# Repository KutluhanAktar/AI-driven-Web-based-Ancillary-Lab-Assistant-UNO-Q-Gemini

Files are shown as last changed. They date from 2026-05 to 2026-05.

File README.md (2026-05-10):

> I developed my portfolio website — kutluhanaktar.com — from scratch and decided to migrate all of my codebase to GitHub to provide a simple and straightforward experimentation or replication method for my proof-of-concept projects. Nonetheless, since I focused on demonstrating my thought process and experiment results thoroughly in the written tutorial format, including but not limited to PCB and 3D model designing steps, I could not provide enough information to fully explain my concepts and instructions via GitHub descriptions only. Thus, I highly recommend inspecting the associated project tutorials and videos on my portfolio website or other platforms (maker communities), i.e., Hackster, Hackaday, and Instructables.

# Original Project Publication Date

**May 10, 2026**

# Description

**Based on Arduino UNO Q, this lab assistant is able to show real-time sensor readings, identify users by fingerprint, recognize lab equipment via object detection, generate AI lessons via Gemini, and talk through its full-fledged web dashboard.**

After hearing about the launch of the brand-new Arduino UNO Q, designed as the first SBC (single-board computer) with Arduino's philosophy of bridging the gap between employing professional development tools and implementing them as novices when creating introductory projects or as experts while prototyping complex mechanisms rapidly yet stably, I thought it would be a great opportunity to redesign my previous AI-driven lab assistant project and enable more developers, beginner or expert, to replicate, experiment, or improve this new AI-based ancillary lab assistant thanks to the built-in Arduino UNO Q features and its beginner-friendly development platform — Arduino App Lab.

As you may know, if you have read one of my previous project tutorials, I prefer building my AIoT projects on the target development boards and environments from scratch and enjoy developing unique methods, applications, and mechanisms to collect custom training data and achieve intended device features, strictly following my methodology of developing proof-of-concept research projects. Nonetheless, in this project, I heavily focused on developing all lab assistant features based on the provided UNO Q and Arduino App Lab characteristics, such as the built-in Bricks, native microprocessor-microcontroller communication procedure, and Linux-oriented SBC board architecture, to ensure that anyone with a UNO Q can effortlessly replicate and examine this lab assistant without needing to have a deep understanding of all aspects of this project; coding, web design, neural network training, LLM-implementation, 3D modeling, etc. In this regard, I hope this project serves as an entry point for developing research projects, encouraging readers to reverse-engineer the features of this AI-driven lab assistant to gain a deeper understanding of AIoT development on the edge.

As I was taking inspiration from my previous lab assistant project, I heavily modified the device structure and added a lot of new features specific to this iteration, for instance, designing a unique PCB (UNO Q shield) for utilizing various lab sensors to conduct LLM-assisted basic lab experiments. After months of hard work, I managed to complete the reimagined AI-driven ancillary lab assistant structure and develop all the features I envisioned on UNO Q by solely employing the Arduino App Lab development environment, providing foundational building blocks (Bricks).

🤖 To build the ancillary lab assistant structure:

✍🏻 I designed a unique PCB as a UNO Q shield (hat) to connect the selected lab sensors and create the analog lab assistant interface, including the capacitive fingerprint sensor.

✍🏻 Then, I modeled 3D parts to design the ancillary lab assistant base, containing the USB camera and the analog interface.

✍🏻 Finally, I designed a modular lab sensor ladder, organizing all sensors and secondary experiment tools, to create a compact but easy-to-use instrument.

🤖 To accomplish all of the ancillary lab assistant features I contemplated, performed by an Arduino App Lab application:

🛠️ I trained an Edge Impulse object detection model to identify various lab equipment.

🛠️ I programmed the MCU (STM32) to collect real-time sensor information and manage the analog lab assistant interface.

🛠️ I developed a feature-rich web dashboard as the primary user interface and control panel of the lab assistant, hosted directly by the Arduino App Lab.

🛠️ I incorporated Google Gemini to enable the lab assistant to generate LLM-based lessons about the detected lab equipment.

🛠️ Thanks to the built-in background Linux MPU-MCU communication service (Arduino Router), I built the interconnected interface background in Python, handling the data transfer between the web dashboard, the analog interface (MCU), and the Qualcomm QRB (MPU) running the essential App Lab Bricks (Docker containers); database registration, inference running, web dashboard (UI) hosting, etc.

🤖 The finalized ancillary lab assistant allows users to:

🔬 create web dashboard accounts and sign in via fingerprint authentication,

🔬 monitor real-time lab sensor readings via the analog interface or the web dashboard,

🔬 inspect LLM-generated sensor guides and experiment tips for each lab sensor via the web dashboard,

🔬 capitalizing on the built-in browser text-to-speech (TTS) module, listen to LLM-generated sensor guides and experiment tips,

🔬 identify lab equipment via the provided Edge Impulse FOMO object detection model,

🔬 use the predefined equipment questions or enter a specific one to generate AI lessons through Google Gemini,

🔬 access the list of LLM-generated lessons assigned to your account on the web dashboard anytime,

🔬 study LLM-generated lessons by reading or listen to them via the TTS module.

# Inspect the project tutorial on:

- **[kutluhanaktar.com](https://www.kutluhanaktar.com/projects/AI_driven_Ancillary_Lab_Assistant_w_UNO_Q_and_Gemini/)**
- **[Hackster](https://www.hackster.io/kutluhan-aktar/ai-driven-web-based-ancillary-lab-assistant-uno-q-gemini-b6d539)**
- **[Instructables](https://www.instructables.com/AI-driven-Web-based-Ancillary-Lab-Assistant-UNO-Q-/)**
- **[Hackaday](https://hackaday.io/project/205671-ai-driven-web-based-lab-assistant-uno-q-gemini)**

pcb_solder_7 <br>

model_design_24_overall <br>

model_design_25_overall <br>

assembly_8_base <br>

assembly_15_base <br>

assembly_50_sensor_ladder <br>

pcb_base_set_2 <br>

pcb_base_set_12_cable_ties <br>

pcb_base_set_13_cable_ties <br>

pcb_connect_test_3 <br>

pcb_connect_test_5 <br>

pcb_connect_test_6 <br>

analog_exp_3_prepare <br>

pcb_connect_test_7 <br>

final_showcase_with_equ_1 <br>

analog_run_2_manual_sensor <br>

web_dashboard_work_2_sensor <br>

web_dashboard_work_4_sensor <br>

analog_run_4_dashboard_sensor <br>

web_dashboard_work_30_sensor_exp_talk <br>

analog_exp_5_pressure <br>

web_dashboard_work_33_sensor_show_exps <br>

analog_exp_7_alcohol <br>

web_dashboard_work_35_sensor_show_exps <br>

analog_exp_9_weight <br>

web_dashboard_work_37_sensor_show_exps <br>

web_dashboard_work_39_sensor_show_exps <br>

analog_exp_11_water <br>

analog_exp_18_gnss_found_signal <br>

analog_exp_20_gnss_found_signal <br>

web_dashboard_work_gnss_found_full_signal_2 <br>

web_dashboard_work_44_gemini_lesson <br>

web_dashboard_work_47_gemini_lesson <br>

analog_account_register_1 <br>

analog_account_register_5 <br>

analog_account_register_6 <br>

analog_lesson_3_prepare <br>

analog_lesson_4_prepare <br>

web_dashboard_work_54_gemini_lesson <br>

web_dashboard_work_55_gemini_lesson <br>

web_dashboard_work_56_gemini_lesson <br>

web_dashboard_work_59_gemini_lesson <br>

web_dashboard_work_60_gemini_lesson <br>

web_dashboard_work_72_gemini_lesson_custom_question <br>

web_dashboard_work_74_gemini_lesson_custom_question <br>

web_dashboard_work_76_gemini_lesson_custom_question <br>

web_dashboard_work_67_save_new_sample <br>

web_dashboard_work_69_save_new_sample <br>

web_dashboard_work_88_signin <br>

analog_account_verify_1_not_f <br>

analog_account_verify_6_success <br>

analog_account_verify_7_success <br>

web_dashboard_work_91_signin <br>

web_dashboard_work_92_signin <br>

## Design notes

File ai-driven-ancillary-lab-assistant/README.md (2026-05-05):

# 🔬 AI-driven Web-based Ancillary Lab Assistant | UNO Q & Gemini

### Based on Arduino UNO Q, this lab assistant is able to show real-time sensor readings, identify users by fingerprint, detect lab equipment via object detection, generate AI lessons via Gemini, and talk through its full-fledged web dashboard.

Please visit the thorough project tutorial on ***Hackster*** for more information:

[Project Tutorial](https://www.hackster.io/kutluhan-aktar/ai-driven-web-based-ancillary-lab-assistant-uno-q-gemini-b6d539)

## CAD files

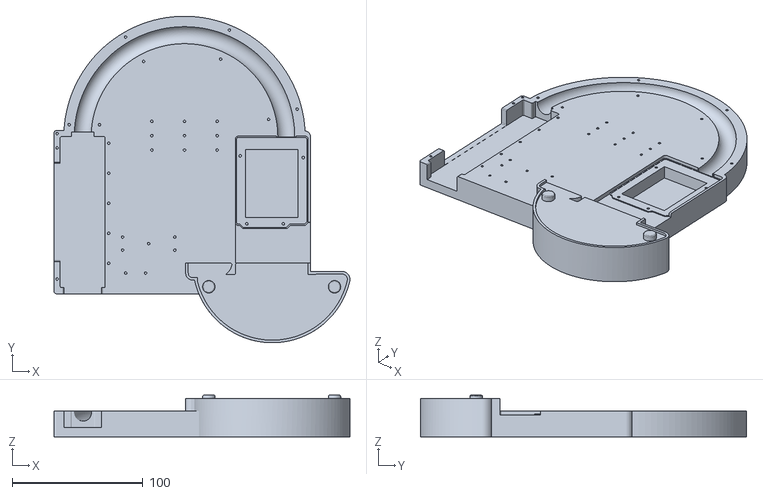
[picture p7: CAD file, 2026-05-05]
3D_part_and_component_design_files/AI_driven_lab_assistant_uno_q v23_AI_driven_lab_assistant_uno_q v23_assistant_base.stl
226.8 x 250.2 x 32.0

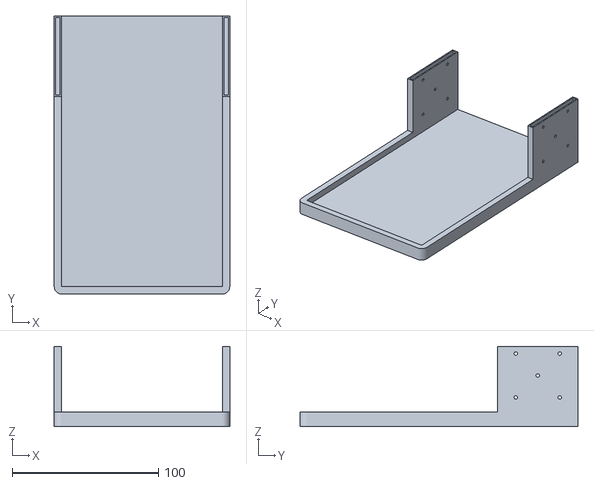
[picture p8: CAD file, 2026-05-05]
3D_part_and_component_design_files/AI_driven_lab_assistant_uno_q v23_AI_driven_lab_assistant_uno_q v23_Lab_Sensors_Ladder_1_sensor_ladder_base.stl
120.0 x 190.0 x 55.0

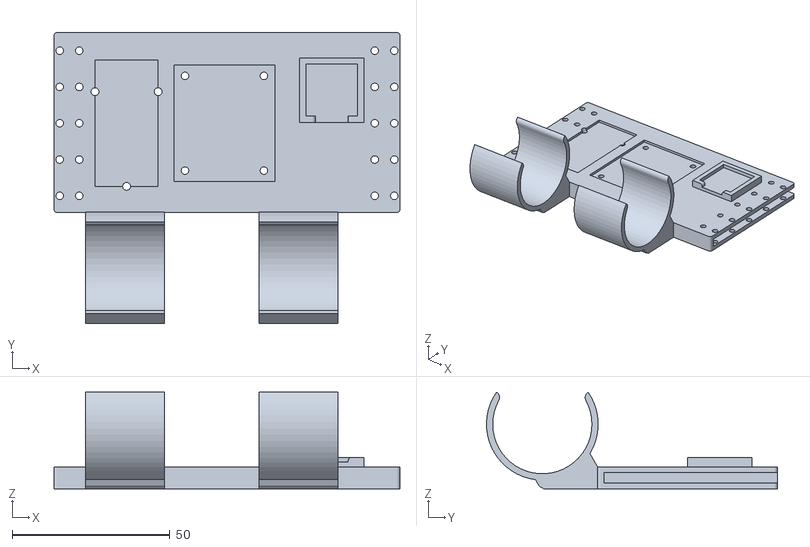
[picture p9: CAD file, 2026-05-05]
3D_part_and_component_design_files/AI_driven_lab_assistant_uno_q v23_AI_driven_lab_assistant_uno_q v23_Lab_Sensors_Ladder_1_row_third.stl
109.6 x 92.2 x 30.7

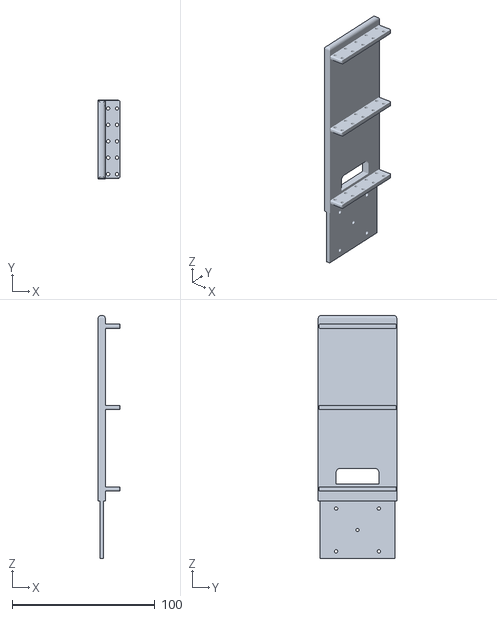
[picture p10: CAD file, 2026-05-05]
3D_part_and_component_design_files/AI_driven_lab_assistant_uno_q v23_AI_driven_lab_assistant_uno_q v23_Lab_Sensors_Ladder_1_ladder_left.stl
15.2 x 55.0 x 170.2

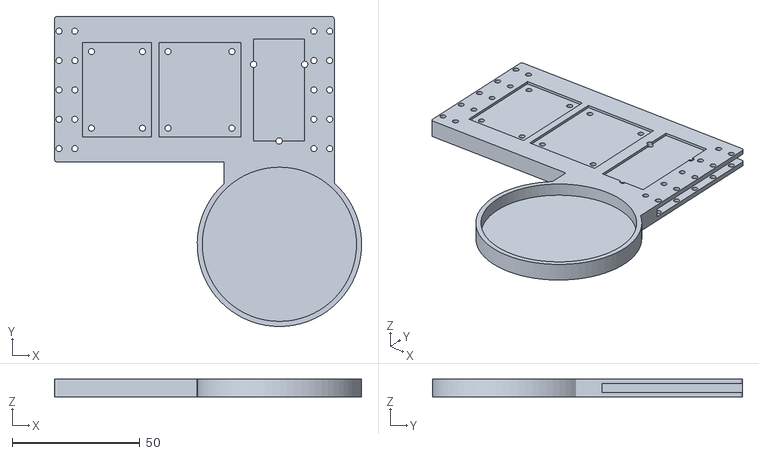
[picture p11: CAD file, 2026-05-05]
3D_part_and_component_design_files/AI_driven_lab_assistant_uno_q v23_AI_driven_lab_assistant_uno_q v23_Lab_Sensors_Ladder_1_row_second.stl
120.3 x 121.4 x 7.00

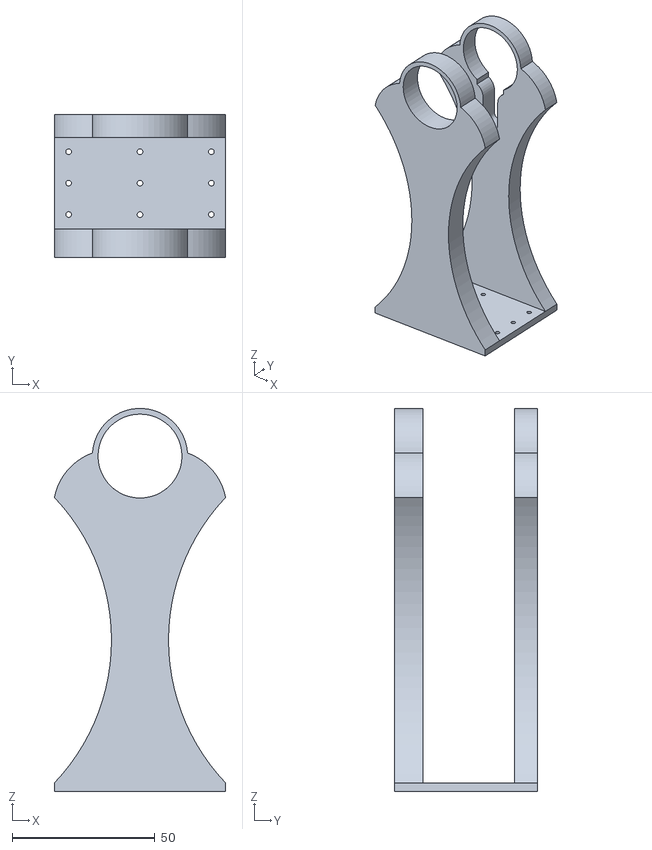
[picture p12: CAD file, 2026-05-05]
3D_part_and_component_design_files/AI_driven_lab_assistant_uno_q v23_AI_driven_lab_assistant_uno_q v23_usb_camera_holder.stl
60.0 x 50.0 x 134.2

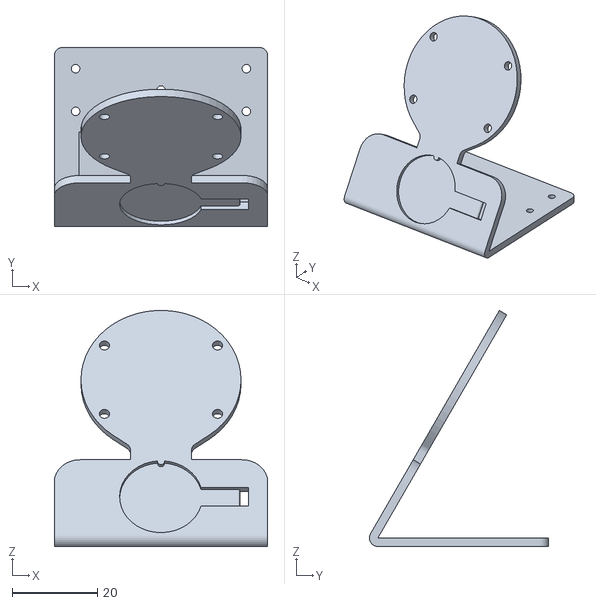
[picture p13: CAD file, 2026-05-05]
3D_part_and_component_design_files/AI_driven_lab_assistant_uno_q v23_AI_driven_lab_assistant_uno_q v23_round_screen_and_fingerprint_sensor_holder.stl
50.0 x 42.0 x 55.3

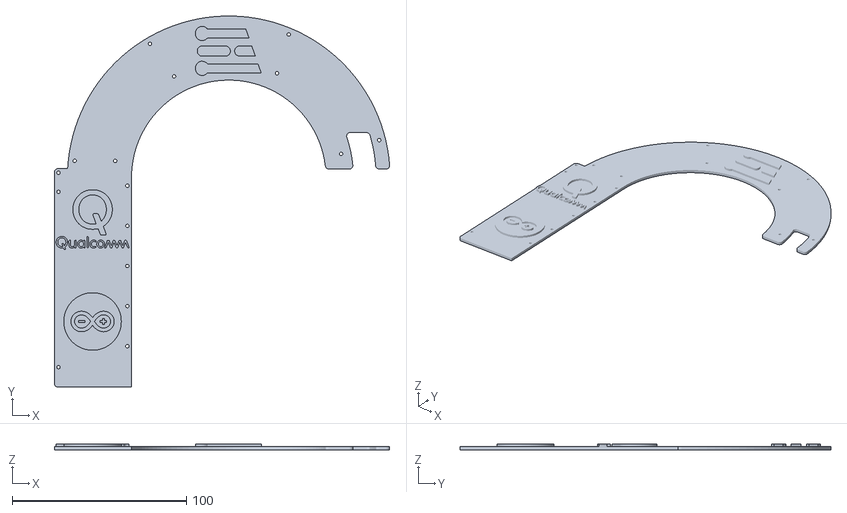
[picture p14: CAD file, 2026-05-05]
3D_part_and_component_design_files/AI_driven_lab_assistant_uno_q v23_AI_driven_lab_assistant_uno_q v23_usb_hub_cover.stl
192.2 x 212.7 x 3.50

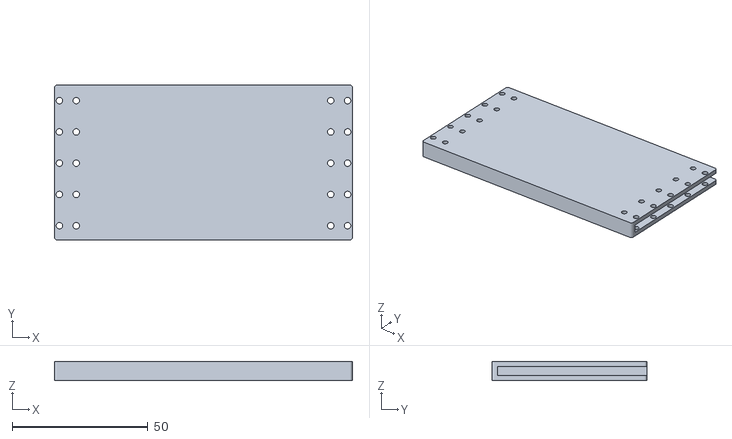
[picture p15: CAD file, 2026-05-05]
3D_part_and_component_design_files/AI_driven_lab_assistant_uno_q v23_AI_driven_lab_assistant_uno_q v23_Lab_Sensors_Ladder_1_row_first.stl
109.6 x 57.0 x 7.00

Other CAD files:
3D_part_and_component_design_files/AI_driven_lab_assistant_uno_q v23_AI_driven_lab_assistant_uno_q v23_Lab_Sensors_Ladder_1_ladder_right.stl

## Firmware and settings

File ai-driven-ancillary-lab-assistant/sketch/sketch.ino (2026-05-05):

         /////////////////////////////////////////////  
        //     AI-driven Web-based Ancillary       //
       //     Lab Assistant | UNO Q & Gemini      //
      //             ---------------             //
     //             (Arduino UNO Q)             //           
    //             by Kutluhan Aktar           // 
   //                                         //
  /////////////////////////////////////////////

//
// Based on Arduino UNO Q, this lab assistant is able to show real-time sensor readings, identify users by fingerprint, detect lab equipment via object detection, generate AI lessons via Gemini, and talk through its full-fledged web dashboard.
//
// For more information:
// https://www.hackster.io/kutluhan-aktar/ai-driven-web-based-ancillary-lab-assistant-uno-q-gemini-b6d539
//
//
// Connections
// Arduino UNO Q :  
//                                Capacitive Fingerprint Sensor (UART)
// 3.3V    ------------------------ VIN
// GND     ------------------------ GND
// D1 / USART1_TX ----------------- RX
// D0 / USART1_RX ----------------- TX
// 3.3V    ------------------------ 3V3
//                                Gravity: Electrochemical Alcohol Sensor
// 3.3V    ------------------------ +
// GND     ------------------------ -
// SCL     ------------------------ C/R
// SDA     ------------------------ D/T
//                                Gravity: 1Kg Weight Sensor Kit - HX711
// 3.3V    ------------------------ VCC
// GND     ------------------------ GND
// SCL     ------------------------ SCL
// SDA     ------------------------ SDA
//                                Gravity: Geiger Counter Module - Ionizing Radiation Detector
// GND     ------------------------ -
// 3.3V    ------------------------ +
// D2      ------------------------ D
//                                Gravity: Electrochemical Nitrogen Dioxide Sensor - NO2
// 3.3V    ------------------------ +
// GND     ------------------------ -
// SCL     ------------------------ C/R
// SDA     ------------------------ D/T
//                                Grove - Integrated Pressure Sensor Kit - MPX5700AP
// GND     ------------------------ GND
// 3.3V    ------------------------ VCC
// A0      ------------------------ SIG
//                                Grove - Water Atomization Sensor - Ultrasonic
// GND     ------------------------ GND
// 5V      ------------------------ VCC
// D4      ------------------------ EN
//                                Gravity: GNSS Positioning Module
// 3.3V    ------------------------ +
// GND     ------------------------ -
// SCL     ------------------------ C/R
// SDA     ------------------------ D/T
//                                Waveshare - 1.28inch Round LCD Display Module
// 3.3V    ------------------------ VCC
// GND     ------------------------ GND
// D11     ------------------------ DIN
// D13     ------------------------ CLK
// D10     ------------------------ CS
// D7      ------------------------ DC
// D8      ------------------------ RST
// D9      ------------------------ BL
//                                Control Button (A)
// A1      ------------------------ +
//                                Control Button (B)
// A2      ------------------------ +
//                                Control Button (C)
// A3      ------------------------ +
//                                Control Button (D)
// A4      ------------------------ +
//                                5mm Common Anode RGB LED
// D3      ------------------------ R
// D5      ------------------------ G
// D6      ------------------------ B


// Include the required libraries:
#include <Arduino_RouterBridge.h>
#include <DFRobot_ID809.h>
#include "DFRobot_Alcohol.h"
#include <DFRobot_HX711_I2C.h>
#include "DFRobot_MultiGasSensor.h"
#include <DFRobot_Geiger.h>
#include "DFRobot_GNSS.h"
#include "SPI.h"
#include "Adafruit_GFX.h"
#include "Adafruit_GC9A01A.h"

// Import the custom menu (interface) logos — icons.
#include "logo.h"

// Import the custom color theme.
#include "color_theme.h"

// Define the round LCD (GC9A01) screen configurations and declare the GC9A01 class instance.
#define SCREEN_WIDTH   240
#define SCREEN_HEIGHT  240
#define TFT_DC         D7
#define TFT_CS         D10
Adafruit_GC9A01A tft(TFT_CS, TFT_DC);

// Define the class instance for the capacitive fingerprint sensor (UART).
DFRobot_ID809 fingerprint;

// Define the configurations and the class instance for the Geiger counter module (ionizing radiation).
#define geiger_detect_pin D2
DFRobot_Geiger geiger(geiger_detect_pin);

// Define the configurations and the class instance for the electrochemical alcohol sensor.
/*
  1) The available collection range is between 1 and 100. The sensor generates the final result as the average of the given number (collection range) of the latest data collection array items.
 
  2) The available I2C addresses are as follows. Please use the onboard the DIP switch to change the default I2C address. 
                        | A0 | A1 |  
    ALCOHOL_ADDRESS_0   | 0  | 0  |   0x72
    ALCOHOL_ADDRESS_1   | 1  | 0  |   0x73
    ALCOHOL_ADDRESS_2   | 0  | 1  |   0x74
    ALCOHOL_ADDRESS_3   | 1  | 1  |   0x75 (Default)
*/
#define alcohol_collect_num  10
DFRobot_Alcohol_I2C alcohol_sensor(&Wire, ALCOHOL_ADDRESS_3);

// Define the configurations and the class instance for the electrochemical nitrogen dioxide (NO2) sensor.
/*
  1) The available I2C addresses are as follows. Please use the onboard the DIP switch to change the default I2C address.
    | A0 | A1 |  
    | 0  | 0  |   0x74 (Default)
    | 0  | 1  |   0x75
    | 1  | 0  |   0x76
    | 1  | 1  |   0x77    
*/
DFRobot_GAS_I2C no2_gas_sensor(&Wire, 0x74);

// Define the configurations and the class instance for the HX711 weight sensor.
/*
  1) The available I2C addresses are as follows. Please use the onboard the DIP switch to change the default I2C address.
    | A0 | A1 |  
    | 0  | 0  |   0x64 (Default)
    | 1  | 0  |   0x65
    | 0  | 1  |   0x66
    | 1  | 1  |   0x67 
*/
DFRobot_HX711_I2C weight_sensor(&Wire,/*addr=*/0x64);

// Define the configurations and the class instance for the GNSS positioning module
/*
  1) The default I2C address is 0x20.
  2) Once the module acquires a GPS signal successfully, the onboard LED should turn from red to green.
*/
DFRobot_GNSS_I2C gnss_sensor(&Wire ,GNSS_DEVICE_ADDR);

// Declare the required variables to calculate the pressure applied to the integrated pressure sensor (MPX5700AP) by creating a struct — pressure_sensor.
struct pressure_sensor {
  int c_pin = A0;
  int raw_value; 
  const int collection_range = 10;
  const int offset = 410; // zero pressure adjust
  const int full_scale = 9630; // max pressure (span) adjust
};

// Declare the switch pin of the ultrasonic water atomization sensor.
#define water_atomization_pin    D4

// Define the control button pin configurations.
#define control_button_A         A1
#define control_button_B         A2
#define control_button_C         A3
#define control_button_D         A4

// Define the RGB LED pin configurations.
#define red_pin                  D3
#define green_pin                D5
#define blue_pin                 D6

// If you need to print sensor readings and system notifications on the App Lab monitor for debugging, change the __debug_monitor value to true.
volatile boolean __debug_monitor = false;

// Declare the necessary parameters for the sensor readings by creating a struct — sensor_readings. 
struct sensor_readings {
  unsigned long latest_read_time, read_offset = 1000000;
  float pressure;
  float alcohol_concentration;
  float weight;
  struct _no2{ float concentration; int board_temp; }; struct _no2 _no2;
  struct _geiger{ int cpm, nsvh, usvh; }; struct _geiger _geiger;
  struct _gnss{ String date, utc; char lat_dir, lon_dir; double latitude, longitude, altitude, sog, cog; }; struct _gnss _gnss;
  String water_atomization = "OFF";
};

// Define data holders:
struct pressure_sensor pressure_sensor;
struct sensor_readings sensor_readings;
volatile boolean shown_screen_sensor = false;
int current_sensor_screen = 0, total_sensor_screen = 16;
volatile boolean shown_screen_home = false, activated_screen_home = true;
volatile boolean shown_screen_fingerprint = false, activated_screen_fingerprint = false;
String ongoing_fingerprint_task = "check_id";
int provided_user_id = 0;
volatile boolean deleteAllScans = false;


void setup(){
  /*
    Initiate the Arduino Router background Linux service to borrow and run functions between Qualcomm MPU and STM32 MCU interchangeably.
  */
  Bridge.begin();

  // Initiate the integrated App Lab monitor for debugging if necessary.
  //Monitor.begin();

  // Employ the Arduino Router background Linux service to enable Qualcomm MPU to borrow and run these functions on STM32 MCU.
  Bridge.provide("interface_web_control", interface_web_control);
  
  // Initiate the hardware serial port to communicate with the capacitive fingerprint sensor.
  Serial.begin(115200);
  delay(1000);
  
  // Register pin configurations.
  pinMode(control_button_A, INPUT_PULLUP); pinMode(control_button_B, INPUT_PULLUP); pinMode(control_button_C, INPUT_PULLUP); pinMode(control_button_D, INPUT_PULLUP);
  pinMode(red_pin, OUTPUT); pinMode(green_pin, OUTPUT); pinMode(blue_pin, OUTPUT); adjustColor(0,0,0);
  pinMode(water_atomization_pin, OUTPUT); digitalWrite(water_atomization_pin, LOW);
  
  // Initiate the GC9A01 round LCD screen.
  tft.begin();

  // Initiate the fingerprint sensor on the hardware serial port.
  fingerprint.begin(Serial);
  // Check the fingerprint sensor connection status.
  while(fingerprint.isConnected() == false){
    //if(__debug_monitor) Monitor.println("Error => Fingerprint sensor connection failed!");
    show_err_screen("Fingerprint", "Connection Failed!", "UART");
    delay(1000);
  }
  // After conducting experiments with the fingerprint sensor, you can clear the whole fingerprint library — ID (1-80).
  if(deleteAllScans){ fingerprint.delFingerprint(DELALL); delay(1000); }

  // Initiate the electrochemical alcohol sensor and check its connection status.
  while(!alcohol_sensor.begin()){
    //if(__debug_monitor) Monitor.println("Error => Alcohol sensor connection failed!");
    show_err_screen("Alcohol", "Connection Failed!", "I2C");
    delay(1000);
  }
  // Once the alcohol sensor starts, declare its data reading modes: MEASURE_MODE_AUTOMATIC (default) or MEASURE_MODE_PASSIVE.
  alcohol_sensor.setModes(MEASURE_MODE_AUTOMATIC);

  // Initiate the HX711 weight sensor and check its connection status.
  while (!weight_sensor.begin()) {
    //if(__debug_monitor) Monitor.println("Error => Weight sensor connection failed!");
    show_err_screen("Weight", "Connection Failed!", "I2C");
    delay(1000);
  }
  // Once the weight sensor starts, assign the calibration weight value (g) and the calibration trigger threshold value (g) for automatic calibration.
  weight_sensor.setCalWeight(50);
  weight_sensor.setThreshold(30);
  weight_sensor.setCalibration(weight_sensor.getCalibration());
  delay(1000);

  // Initiate the electrochemical nitrogen dioxide (NO2) gas sensor and check its connection status.
  while(!no2_gas_sensor.begin()){
    //if(__debug_monitor) Monitor.println("Error => NO2 gas sensor connection failed!");
    show_err_screen("NO2", "Connection Failed!", "I2C");
    delay(1000);
  }
  // Once the NO2 gas sensor starts, declare its data reading mode: INITIATIVE or PASSIVITY.
  no2_gas_sensor.changeAcquireMode(no2_gas_sensor.PASSIVITY); delay(1000);
  no2_gas_sensor.setTempCompensation(no2_gas_sensor.OFF); // ON or OFF
   
  // Initiate the GNSS positioning module and check its connection status.
  while(!gnss_sensor.begin()){
    //if(__debug_monitor) Monitor.println("Error => GNSS module connection failed!");
    show_err_screen("GNSS", "Connection Failed!", "I2C");
    delay(1000);
  }
  // Once the GNSS module starts, define its essential configurations.
  gnss_sensor.enablePower();
  /*
    1) Available combinations to select GNSS bands to acquire information are as follows.
      eGPS              use gps
      eBeiDou           use beidou
      eGPS_BeiDou       use gps + beidou
      eGLONASS          use glonass
      eGPS_GLONASS      use gps + glonass
      eBeiDou_GLONASS   use beidou +glonass
      eGPS_BeiDou_GLONASS use gps + beidou + glonass    
  */
  gnss_sensor.setGnss(eGPS_BeiDou_GLONASS);
  gnss_sensor.setRgbOn(); // gnss_sensor.setRgbOff(); 

  // Initiate the Geiger counter module.
  geiger.start();

  // After successfully setting up all sensors, define the current time (microseconds) to perform precise subsequent readings.
  sensor_readings.latest_read_time = micros();

}

void loop(){
  // According to their specific data generation intervals, obtain sensor readings from each sensor without suspending code flow.
  obtain_sensor_readings(sensor_readings.read_offset);

  // Update the current sensor data screen number once the control button A or the control button B is pressed.
  if(!digitalRead(control_button_A)){
    current_sensor_screen++;
    if(current_sensor_screen >= total_sensor_screen) current_sensor_screen = 0;   
    shown_screen_sensor = false;
    activated_screen_home = false; shown_screen_home = false;
    activated_screen_fingerprint = false; shown_screen_fingerprint = false;
    delay(500);
  }

  if(!digitalRead(control_button_B)){
    current_sensor_screen--;
    if(current_sensor_screen < 0) current_sensor_screen = total_sensor_screen-1;   
    shown_screen_sensor = false;
    activated_screen_home = false; shown_screen_home = false;
    activated_screen_fingerprint = false; shown_screen_fingerprint = false;     
    delay(500);
  }  

  // If the home interface or the fingerprint ID test interface are not activated, display the requested sensor data screen.
  if(!activated_screen_home && !activated_screen_fingerprint){
    switch(current_sensor_screen){
      case 0:
        show_sensor_screen("NO2", "Concentration", String(sensor_readings._no2.concentration), "PPM", 0);
      break;
      case 1:
        show_sensor_screen("NO2", "Board Temp.", String(sensor_readings._no2.board_temp), "C", 0);
      break;
      case 2:
        show_sensor_screen("Alcohol", "Concentration", String(sensor_readings.alcohol_concentration), "PPM", 1);
      break; 
      case 3:
        show_sensor_screen("Weight", "Estimation", String(sensor_readings.weight), "G (g)", 2);
      break; 
      case 4:
        show_sensor_screen("Geiger", "Ionizing", String(sensor_readings._geiger.cpm), "CPM", 3);
      break; 
      case 5:
        show_sensor_screen("Geiger", "Ionizing", String(sensor_readings._geiger.nsvh), "nSv/h", 3);
      break;
      case 6:
        show_sensor_screen("Geiger", "Ionizing", String(sensor_readings._geiger.usvh), "uSv/h", 3);
      break; 
      case 7:
        show_sensor_screen("Pressure", "Integrated", String(sensor_readings.pressure), "kPa", 4);
      break;
      case 8:
        show_sensor_screen("Water", "Atomization", sensor_readings.water_atomization, "V", 5);
      break; 
      case 9:
        show_sensor_screen("GNSS", "Date", sensor_readings._gnss.date, "Y/M/D", 6);
      break; 
      case 10:
        show_sensor_screen("GNSS", "UTC", sensor_readings._gnss.utc, "H_M_S", 6);
      break;       
      case 11:
        show_sensor_screen("GNSS", "Latitude", String(sensor_readings._gnss.latitude), "Degrees", 6);
      break; 
      case 12:
        show_sensor_screen("GNSS", "Longitude", String(sensor_readings._gnss.longitude), "Degrees", 6);
      break; 
      case 13:
        show_sensor_screen("GNSS", "Altitude", String(sensor_readings._gnss.altitude), "M (m)", 6);
      break;
      case 14:
        show_sensor_screen("GNSS", "Speed Over Ground", String(sensor_readings._gnss.sog), "SOG", 6);
      break;  
      case 15:
        show_sensor_screen("GNSS", "Course Over Ground", String(sensor_readings._gnss.cog), "COG", 6);
      break;        
    }
  }

  // If the home (main) interface is activated, show it until the user requests to review a sensor data screen or initiate a fingerprint sensor task.
  if(activated_screen_home) show_home_screen();

  // Once the control button D is pressed, return to the home (main) interface.
  if(!digitalRead(control_button_D)) return_home();

  // If a fingerprint sensor task is initiated, show its respective interface until the sensor completes the given task and returns to the home interface.
  while(activated_screen_fingerprint){
    // Start the requested fingerprint sensor task.
    manage_fingerprint_task(ongoing_fingerprint_task, (uint8_t)provided_user_id);    
  }
  
  // If the control button C is pressed, initiate the 'check_id' fingerprint task manually.
  if(!digitalRead(control_button_C)){
    shown_screen_sensor = false;
    activated_screen_home = false; shown_screen_home = false;
    activated_screen_fingerprint = true; shown_screen_fingerprint = false;
    ongoing_fingerprint_task = "check_id";
    delay(500);
  } 
  
}

void obtain_sensor_readings(unsigned long read_offset){
  if(micros() - sensor_readings.latest_read_time >= read_offset){
    pressure_sensor.raw_value = 0;
    for(int x = 0; x < pressure_sensor.collection_range; x++) pressure_sensor.raw_value = pressure_sensor.raw_value + analogRead(pressure_sensor.c_pin);
    sensor_readings.pressure = (pressure_sensor.raw_value - pressure_sensor.offset) * 700.0 / (pressure_sensor.full_scale - pressure_sensor.offset);
    //if(__debug_monitor){Monitor.print("Pressure sensor raw value (A/D) is  "); Monitor.print(pressure_sensor.raw_value); Monitor.print("\nEstimated pressure is "); Monitor.print(sensor_readings.pressure);  Monitor.println(" kPa\n");}    
  }
  if(micros() - sensor_readings.latest_read_time >= 2*read_offset){
    sensor_readings.alcohol_concentration = alcohol_sensor.readAlcoholData(alcohol_collect_num);
    if(sensor_readings.alcohol_concentration == ERROR) sensor_readings.alcohol_concentration = -1;
    //if(__debug_monitor){ Monitor.print("Alcohol concentration is "); Monitor.print(sensor_readings.alcohol_concentration); Monitor.println(" PPM.\n"); }
  }
  if(micros() - sensor_readings.latest_read_time >= 3*read_offset){
    sensor_readings.weight = weight_sensor.readWeight();
    if(sensor_readings.weight < 0.5) sensor_readings.weight = 0;
    //if(__debug_monitor){ Monitor.print("Estimated weight is "); Monitor.print(sensor_readings.weight); Monitor.println(" g.\n"); }
    sensor_readings._geiger.cpm = geiger.getCPM();
    sensor_readings._geiger.nsvh = geiger.getnSvh();
    sensor_readings._geiger.usvh = geiger.getuSvh();
    //if(__debug_monitor){Monitor.print("CPM: "); Monitor.println(sensor_readings._geiger.cpm); Monitor.print("nSv/h: "); Monitor.println(sensor_readings._geiger.nsvh); Monitor.print("μSv/h "); Monitor.println(sensor_readings._geiger.usvh);}
  }
  if(micros() - sensor_readings.latest_read_time >= 4*read_offset){
    sensor_readings._no2.concentration = no2_gas_sensor.readGasConcentrationPPM();
    sensor_readings._no2.board_temp = no2_gas_sensor.readTempC();
    //if(__debug_monitor){ Monitor.print("NO2 concentration is: "); Monitor.print(sensor_readings._no2.concentration); Monitor.println(" PPM\n"); Monitor.print("NO2 sensor board temperature is: "); Monitor.print(sensor_readings._no2.board_temp); Monitor.println(" ℃\n"); }
  }
  if(micros() - sensor_readings.latest_read_time >= 5*read_offset){
    sTim_t utc = gnss_sensor.getUTC();
    sTim_t date = gnss_sensor.getDate();
    sLonLat_t lat = gnss_sensor.getLat();
    sLonLat_t lon = gnss_sensor.getLon();
    sensor_readings._gnss.date = String(date.year) + "/" + String(date.month) + "/" + String(date.date); sensor_readings._gnss.utc = String(utc.hour) + "_" + String(utc.minute) + "_" + String(utc.second);
    sensor_readings._gnss.lat_dir = (char)lat.latDirection; sensor_readings._gnss.lon_dir = (char)lon.lonDirection;
    sensor_readings._gnss.latitude = lat.latitudeDegree; sensor_readings._gnss.longitude = lon.lonitudeDegree;
    sensor_readings._gnss.altitude = gnss_sensor.getAlt();
    sensor_readings._gnss.sog = gnss_sensor.getSog(); // Speed Over Ground
    sensor_readings._gnss.cog = gnss_sensor.getCog(); // Course Over Ground
    //if(__debug_monitor){ Monitor.print("GNSS (latitude): ");  Monitor.print(sensor_readings._gnss.latitude); Monitor.print("GNSS (longitude): ");  Monitor.print(sensor_readings._gnss.longitude); Monitor.print("GNSS (altitude): ");  Monitor.print(sensor_readings._gnss.altitude); }
  }
  if(micros() - sensor_readings.latest_read_time >= 6*read_offset){
    // After collecting all sensor variables, invoke the borrowed Python function via the Arduino Router using MessagePack RPC.
    Bridge.call("update_sensor_on_app", sensor_readings.pressure, sensor_readings.alcohol_concentration, sensor_readings.weight, sensor_readings._no2.concentration, sensor_readings._no2.board_temp, sensor_readings._geiger.cpm, sensor_readings._geiger.nsvh, sensor_readings._geiger.usvh, sensor_readings._gnss.date, sensor_readings._gnss.utc, sensor_readings._gnss.lat_dir, sensor_readings._gnss.lon_dir, sensor_readings._gnss.latitude, sensor_readings._gnss.longitude, sensor_readings._gnss.altitude, sensor_readings._gnss.sog, sensor_readings._gnss.cog);
    // Restart the sensor reading timer.
    sensor_readings.latest_read_time = micros();    
  }
}
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

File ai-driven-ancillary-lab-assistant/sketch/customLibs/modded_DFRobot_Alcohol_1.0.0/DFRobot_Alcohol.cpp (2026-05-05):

/*!
 * @file DFRobot_Alcohol.cpp
 * @brief Define the basic structure of the DFRobot_Alcohol class, the implementation of the basic methods
 * @copyright	Copyright (c) 2010 DFRobot Co.Ltd (http://www.dfrobot.com)
 * @license The MIT License (MIT)
 * @author [ZhixinLiu](zhixin.liu@dfrobot.com)
 * @version V1.0
 * @date 2020-09-09
 * @url https://github.com/DFRobot/DFRobot_Alcohol
 */
#include "DFRobot_Alcohol.h"

DFRobot_Alcohol::DFRobot_Alcohol(){}
DFRobot_Alcohol::~DFRobot_Alcohol(){}

void DFRobot_Alcohol::writeAlcohol(uint8_t reg, uint8_t pdata)
{
  if(uartI2CFlag == I2C_FLAG){
    sendBuf[0] = pdata;
    writeData(reg, sendBuf, 1);
  }else{
    if(pdata == MEASURE_MODE_AUTOMATIC){
      writeData(reg, cmdALOHA, 9);
    }else if(pdata == MEASURE_MODE_PASSIVE){
      writeData(reg, cmdPolling, 9);
    }
  }
}

void DFRobot_Alcohol::writeAlcohol_R(uint8_t reg, uint8_t pdata)
{
  if(uartI2CFlag == I2C_FLAG){
    sendBuf[0] = pdata;
    writeData(reg, sendBuf, 1);
  }
}

int16_t DFRobot_Alcohol::readAlcohol(uint8_t reg)
{
  if(uartI2CFlag == I2C_FLAG){
    if(-1 == readData(reg, readBuf, 2)){
      return -1;
    }else{
      return ((int16_t)readBuf[0] << 8) + readBuf[1];
    }
  }else{
    if(reg == AUTO_DATA_HIGE_REGISTER){
      readData(0, readBuf, DATA_LEN);
      if(readBuf[0] == 0xFF && readBuf[1] == 0x17){
        return ((int16_t)readBuf[4] << 8) + readBuf[5];
      }else{
        return -1;
      }
    }else if(reg == PASS_DATA_HIGE_REGISTER){
      writeData(0, cmdRead, DATA_LEN);
      readData (0, readBuf, DATA_LEN);
      if(readBuf[0] == 0xFF && readBuf[1] == 0x86){
        return ((int16_t)readBuf[6] << 8) + readBuf[7];
      }else{
        return -1;
      }
    }
  }
  return 0;
}

void DFRobot_Alcohol::setModes(uint8_t mode)
{
  if(mode == MEASURE_MODE_AUTOMATIC){
    writeAlcohol(MODE_REGISTER,  MEASURE_MODE_AUTOMATIC);
    delay(100);   _M_Flag = 0;
  }else if (mode == MEASURE_MODE_PASSIVE){
    writeAlcohol(MODE_REGISTER,  MEASURE_MODE_PASSIVE);
    delay(100);   _M_Flag = 1;
  }else {
    return;
  }
}

float DFRobot_Alcohol::readAlcoholData(uint8_t collectNum)
{
  static uint8_t i = 0, j = 0;
  if (collectNum > 0) {
    for(j = collectNum - 1;  j > 0; j--) {  alcoholData[j] = alcoholData[j-1]; }
    if(_M_Flag == 0){
      writeAlcohol_R(SET_PASSIVE_REGISTER,  AUTO_READ_DATA);      delay(100);
      alcoholData[0] = readAlcohol(AUTO_DATA_HIGE_REGISTER);
      if(alcoholData[0] == -1) {
        memset(alcoholData,0,collectNum);
        i = 0;
        j = 0;
        return -1;
      }
    }else if(_M_Flag == 1){
      writeAlcohol_R(SET_PASSIVE_REGISTER,  PASSIVE_READ_DATA);   delay(100);
      alcoholData[0] = readAlcohol(PASS_DATA_HIGE_REGISTER);
      if(alcoholData[0] == -1) {
        memset(alcoholData,0,collectNum);
        i = 0;
        j = 0;
        return -1;
      }
    }
    if(i < collectNum) i++;
    return getAverageNum(alcoholData, i);
  }else if(collectNum <= 0 || collectNum > 100){
   return -1;
  }
  return 0.0;
}

float DFRobot_Alcohol::getAverageNum(int bArray[], int iFilterLen) 
{
  uint8_t i = 0;
  unsigned long bTemp = 0;
  for(i = 0; i < iFilterLen; i++){
    bTemp += bArray[i];
  }
  return (float)(bTemp / iFilterLen) / 1000.0;
}

DFRobot_Alcohol_I2C::DFRobot_Alcohol_I2C(TwoWire *pWire, uint8_t addr)
{
  _pWire = pWire;
  this->_I2C_addr = addr;
  uartI2CFlag = I2C_FLAG;
}

bool DFRobot_Alcohol_I2C::begin()
{
  _pWire->begin();
  _pWire->beginTransmission(_I2C_addr);
  if(_pWire->endTransmission() == 0){
    return true;
  }else{
    return false;
  }
}

void DFRobot_Alcohol_I2C::writeData(uint8_t reg, uint8_t *data, uint8_t len)
{
  _pWire->beginTransmission(this->_I2C_addr);
  _pWire->write(reg);
  for(uint8_t i = 0; i < len; i++){
    _pWire->write(data[i]);
  }
  _pWire->endTransmission();
}

int16_t DFRobot_Alcohol_I2C::readData(uint8_t reg,uint8_t *data,uint8_t len)
{
  int i=0;
  _pWire->beginTransmission(this->_I2C_addr);
  _pWire->write(reg);
  if(_pWire->endTransmission() != 0){
    return -1;
  }
  _pWire->requestFrom((uint8_t)this->_I2C_addr,(uint8_t)len);
  while (_pWire->available()){
    data[i++]=_pWire->read();
  }
  return 0;
}

#ifdef ESP_PLATFORM
  DFRobot_Alcohol_UART::DFRobot_Alcohol_UART(HardwareSerial *hSerial, uint16_t Baud)
  {
    this->_serial = hSerial;
    this->_baud = Baud;
    uartI2CFlag = UART_FLAG;
  }
#else
  DFRobot_Alcohol_UART::DFRobot_Alcohol_UART(HardwareSerial *sSerial, uint16_t Baud)
  {
    this->_serial = sSerial;
    this->_baud = Baud;
    uartI2CFlag = UART_FLAG;
  }
#endif

bool DFRobot_Alcohol_UART::begin()
{
  _serial->begin(this->_baud);
  this->writeData(0,cmdALOHA,DATA_LEN);
  this->readData (0,readBuf,DATA_LEN);
  if(readBuf[0] == 0xFF && readBuf[1] == 0x17){
    return true;
  }else{
    return false;
  }
}

void DFRobot_Alcohol_UART::writeData(uint8_t reg, uint8_t *data, uint8_t len)
{
  uint8_t i = 0;
  for(i = 0; i < len; i++){
    _serial->print((char)data[i]);
  }
}

int16_t DFRobot_Alcohol_UART::readData(uint8_t reg, uint8_t *data, uint8_t len)
{
  uint8_t i = 0;
  memset(readBuf,0,DATA_LEN);
  uint32_t nowtime = millis();
  while(millis() - nowtime < TIME_OUT){
    while(_serial->available() > 0){
      readBuf[i++] = _serial->read();
    }
  }
  return 0;
}
